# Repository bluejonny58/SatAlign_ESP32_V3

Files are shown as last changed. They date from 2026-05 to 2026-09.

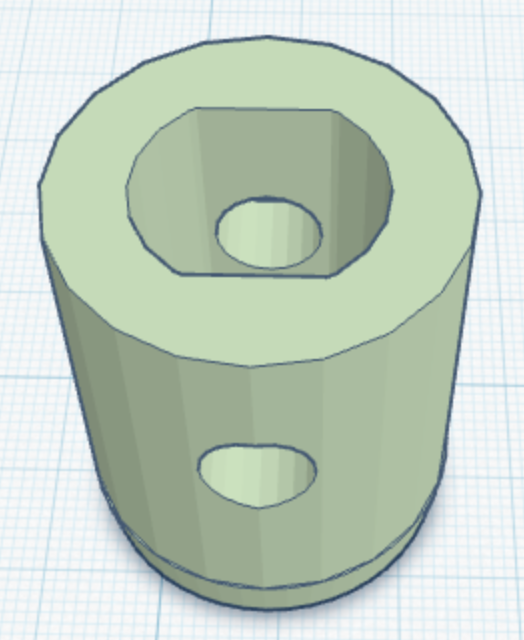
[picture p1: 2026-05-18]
images/Adapter.png

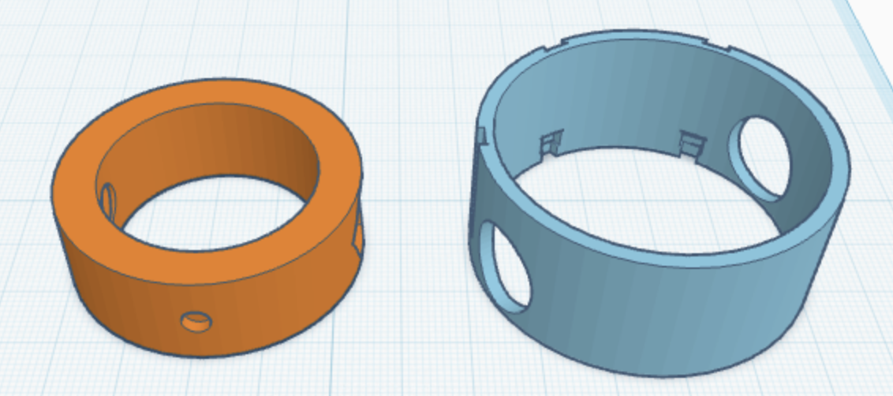
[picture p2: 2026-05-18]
images/Hall_Ringe.png

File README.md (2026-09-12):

# SatAlign ESP32 V3

**ESP32-basierte manuelle und automatische Ausrichthilfe fuer eine mobile Selfsat-Flachantenne.**

SatAlign verbindet Azimut- und Elevationssteuerung, Hall-Sensorik, MPU6050-Winkelmessung, RF-Signalbewertung, TFT-Bedienung, mobile Web-UI sowie ArduinoOTA und ElegantOTA in einem modularen ESP32-Projekt.

## Aktueller stabiler Stand

**Aktueller Stand: V3.1.5**

V3.1.5 ist der aktuelle Projektstand fuer die Web-Feinjustierung. Die bewaehrte AUTO-Suchlogik aus V3.1.4 bleibt dabei unveraendert. Die Suchlogik basiert auf den praktisch getesteten AUTO-Abläufen ohne nachtraegliche Peak-Rueckfahrt. Experimentelle Peak-Suchvarianten aus spaeteren Tests wurden bewusst nicht uebernommen, weil die Rueckfahrt zum RF-Maximum mit der vorhandenen Mechanik/Positionsschaetzung nicht ausreichend reproduzierbar war.

### Wesentliche Merkmale von V3.1.5

- gemeinsame RF-Prozentbewertung fuer TFT, Web-UI, Diagnose und AUTO-Suche
- `RF_FILTER_ALPHA = 0.50` nach reproduzierbarem RF-/Azimut-Test
- normale AUTO-Kandidatenschwelle: **80 %**
- RF-Anzeige auf maximal **100 %** begrenzt
- dynamische RF-Referenz aus der Centerfahrt bleibt aktiv, darf die 80-%-Mindestgrenze aber nicht unterschreiten
- kompakter, kopierbarer AUTO-Diagnoseblock im seriellen Monitor
- feste IP **192.168.4.15** im Netzwerk `GeniusBulli`
- andere bekannte WLANs per DHCP
- ArduinoOTA und ElegantOTA parallel
- ElegantOTA ueber `/update`
- kein mDNS
- fruehere automatische Funktion **Signal optimieren** aus der Bedienlinie entfernt
- `BADSAT`-Logik zum Sperren bereits verworfener Kandidatenbereiche

## AUTO-Diagnose im seriellen Monitor

Bei einem vollstaendigen AUTO-Lauf erzeugt V3.1.5 einen strukturierten Block bei **115200 Baud**:

```text
# AUTO_LOG_BEGIN
# T_MS;STATE;DIR;RAW;FILTER;SIGNAL;DROP;ZERO_ADC;BEST_ADC;AZPOS;EZ;H_C;H_E;H_W;MIN_RF;CENTER_MIN;BLOCKED
AUTO_LOG;...
...
# AUTO_LOG_RESULT;...
# AUTO_LOG_END
```

Waehrend AUTO werden redundante periodische `RF_DIAG`, grosse `MODE=...`-Statuszeilen und doppelte RF-Diagnosen unterdrueckt. Wichtige Ereignisse - Kandidat, `BADSAT`, Richtungswechsel, Hall-/Limit-Ereignisse, Fehler und Abschluss - bleiben sichtbar.

`AZPOS` ist dabei ein Diagnosewert und kein Encoderwert. Er darf nicht als absolut reproduzierbare mechanische Position verstanden werden.

## RF-Signalbewertung

Beim verwendeten AD8317/AD8318-Aufbau gilt:

- kleinerer ADC-/Spannungswert = staerkeres RF-Signal
- groesserer Prozentwert = staerkeres RF-Signal

Aktuelle zentrale Werte:

```cpp
RF_FILTER_ALPHA = 0.50f;
RF_WEAK_REFERENCE_ADC = 1883.0f;
RF_STRONG_REFERENCE_ADC = 700.0f;
AUTO_RF_MIN_CANDIDATE_PERCENT = 80.0f;
```

Die gemeinsame RF-Prozentbewertung wird auf den normalen Bereich von **0 bis 100 %** begrenzt. Werte, die rechnerisch oberhalb der starken Referenz liegen, werden daher als **100 %** dargestellt. Die 80-%-Grenze bleibt die operative Mindestgrenze fuer normale AUTO-Kandidaten; ein Wert unterhalb davon soll nicht als normaler AUTO-Kandidat akzeptiert werden.

Seit V3.1.5 basiert auch die fuer Nutzer sichtbare Qualitaetsstufe konsequent auf diesem Prozentwert: **< 80 % = schwach**, **80 bis < 85 % = brauchbar**, **85 bis < 95 % = gut**, **ab 95 % = sehr gut**. Auf der Seite **Suchen** stehen deshalb Prozentwert und Qualitaet im Vordergrund; ADC und Spannung bleiben Diagnosewerte fuer Status/Feinjustierung.

## Lokale Grundeinstellung / Elevation

Nach dem Einschalten startet SatAlign im Hauptmenue. Fuer die grobe Elevationskorrektur wird **Mitte einstellen / Ausrichten** geoeffnet. **PLUS/MINUS** bewegen die Elevation dort nicht dauerhaft, sondern jeweils in einem kurzen Puls von etwa **250 ms**. Wird eine Taste laenger als etwa **800 ms** festgehalten, stoppt die Bewegung und die Tastensperre bleibt bis zum Loslassen aktiv. Ein frueheres 10-Sekunden-Bootfenster fuer die Elevationskorrektur ist im aktuellen V3.1.5-Code nicht mehr vorhanden. **MODE** startet anschliessend die Mittenfahrt.

## Suchablauf

Der automatische Ablauf arbeitet praxisorientiert:

1. Center-/Mittenreferenz herstellen bzw. pruefen.
2. RF waehrend der Mittenfahrt beobachten.
3. Bei einem stabilen brauchbaren Kandidaten anhalten und zur Benutzerpruefung anbieten.
4. Wird kein Kandidat gefunden, die vorgesehene Ost-/West-Suche fortsetzen.
5. **PLUS** bestaetigt den richtigen Satelliten.
6. **MINUS** verwirft den Kandidaten; der Bereich wird fuer die weitere Suche gesperrt (`BADSAT`).

Eine nachtraegliche automatische Peak-Rueckfahrt ist im stabilen Stand V3.1.4 **nicht** enthalten.

## WLAN und OTA

### GeniusBulli

Im Fahrzeug verwendet SatAlign:

- IP: `192.168.4.15`
- Gateway: `192.168.4.1`
- DNS: `192.168.4.1`
- Subnetz: `255.255.255.0`

Bei anderen bekannten WLANs wird DHCP verwendet. Die Reihenfolge in `WIFI_NETWORKS[]` bestimmt die Verbindungsprioritaet.

### Firmware-Updates

Zwei Updatewege sind vorgesehen:

- **ArduinoOTA** fuer Uploads direkt aus der Arduino IDE (Port 3232)
- **ElegantOTA** fuer Browser-Updates ueber `http://192.168.4.15/update`

mDNS wird nicht verwendet. Fuer Web-UI und OTA sollte die IP-Adresse genutzt werden.

## Konfiguration und Zugangsdaten

Private Zugangsdaten gehoeren nicht in das Repository. Vor dem Kompilieren:

1. `secrets.example.h` nach `secrets.h` kopieren.
2. WLAN- und OTA-Daten lokal eintragen.
3. `secrets.h` nicht committen.

Die `.gitignore` ist darauf ausgelegt, lokale Zugangsdaten vom GitHub-Repository fernzuhalten.

## Hardware-Uebersicht

Typischer Projektaufbau:

- ESP32 Development Board
- Selfsat-Flachantenne
- DiSEqC-kompatibler Azimut-Antrieb / Tastensimulation
- Elevations-Linearantrieb mit L298N
- MPU6050 / GY-521
- A3144 Hall-Sensoren fuer Center, Ost und West
- AD8317/AD8318 RF-Detector
- Sat-Splitter / Messabzweig
- **DC-Blocker vor dem RF-Detector**
- ST7735 1,44-Zoll-TFT
- MODE / PLUS / MINUS Taster
- Sat-Receiver

> **Wichtig:** Der DC-Blocker muss vor dem RF-Detector sitzen. Die 13-V-/18-V-LNB-Versorgung des Receivers darf nicht am RF-Detector anliegen.

## Projektstruktur

```text
SatAlign_ESP32_V3/
├── SatAlign_ESP32_V3.ino
├── config.h
├── pins.h
├── settings.cpp / settings.h
├── types.h
├── control_state.cpp / .h
├── azimuth_control.cpp / .h
├── elevation_control.cpp / .h
├── sensor_mpu6050.cpp / .h
├── rf_detector.cpp / .h
├── display_ui.cpp / .h
├── live_runtime.cpp / .h
├── web_server.cpp / .h
├── wifi_manager.cpp / .h
├── ota_manager.cpp / .h
├── wifi_config.h
├── secrets.example.h
├── tools/
│   └── SatAlign_ESP32_V3_InstallTest/
│       └── SatAlign_ESP32_V3_InstallTest.ino
├── docs/
├── images/
└── STL/
```

Arduino-Anforderung: Der Projektordner und die Hauptdatei muessen denselben Namen tragen. Im Repository sind das deshalb `SatAlign_ESP32_V3/` und `SatAlign_ESP32_V3.ino`. Die Firmwareversion steht unabhaengig davon in `FIRMWARE_VERSION` und ist aktuell `3.1.5`.

## InstallTest / Hardwarediagnose

Im Repository bleibt der eigenstaendige Hardwaretest unter

```text
tools/SatAlign_ESP32_V3_InstallTest/SatAlign_ESP32_V3_InstallTest.ino
```

erhalten. Der InstallTest ist **nicht** die normale SatAlign-Firmware, sondern ein Diagnosewerkzeug fuer Erstinbetriebnahme und Hardwareverdacht. Er eignet sich insbesondere, um Taster, TFT, Hall-Sensoren, MPU6050, RF-Detector sowie die Azimut- und Elevationsausgaenge getrennt von der AUTO-Logik zu pruefen.

Wichtig: Auch beim InstallTest gilt die Arduino-Regel, dass Sketch-Datei und Sketch-Ordner denselben Namen tragen. Deshalb liegt die Datei im Unterordner `SatAlign_ESP32_V3_InstallTest/`. Nach dem Hardwaretest muss fuer den normalen Betrieb wieder `SatAlign_ESP32_V3.ino` geflasht werden.

## Web-UI

Die Weboberflaeche bietet unter anderem:

- Hauptmenue
- Ausrichten / Center
- automatische Suche
- manuelle Steuerung mit zusaetzlichen AZ-/EL-Feinschritten fuer die letzte RF-Optimierung
- Status / Diagnose
- Firmware Update (ElegantOTA)

Die Versionsnummer wird auf der Hauptseite angezeigt.

### Manuelle Feinkorrektur

Unter den normalen AZ-/EL-Fahrbuttons stehen zusaetzliche **Fein - / Fein +**-Buttons. Sie starten keine Dauerfahrt, sondern nur sehr kurze Einzelpulse fuer die letzte Optimierung des RF-Maximums. Der aktuelle Arbeitsstand verwendet:

- Azimut-Feinschritt: `WEB_AZ_FINE_PULSE_MS = 50 ms`
- Elevations-Feinschritt: `WEB_EL_FINE_PULSE_MS = 50 ms`
- Elevations-Fein-PWM: `WEB_EL_FINE_PWM = 90`

Bei jeder Achse stehen die **aktuelle Signalstärke und der Feinwert direkt zwischen den beiden Feinbuttons**. Beim Oeffnen der Seite **Manuell** wird automatisch eine neue Referenz fuer die Feinjustierung gesetzt. Bei AZ ist die Referenz `0 Schritte`; darunter wird die relative Position als `0 -> +/-n Schritte` angezeigt. Bei EL wird der aktuelle MPU-Winkel als Referenz gespeichert und danach `Referenz -> aktueller Winkel (Aenderung)` angezeigt. Separate Reset-Buttons und die Puls-/PWM-Werte werden in der Bedienansicht nicht mehr gezeigt.

Der **Feinwert** spreizt den relevanten Signalbereich von 80 bis 100 % linear auf 0 bis 100 % und dient ausschliesslich als Anzeige-Lupe. Eine separate Signalbewertungs-/Diagnosekarte wurde von der manuellen Bedienseite entfernt; die Qualitaetsgrenzen und technischen RF-Rohwerte bleiben in Dokumentation bzw. Diagnosekontext erhalten.

Auch der technische Status wurde reduziert: doppelte Angaben fuer **Web-Zustand** und **Live-Zustand** entfallen. Die Diagnosekarte zeigt nur noch den aktuellen Motorzustand von AZ/EL, die Hall-Sensoren sowie den aktuellen EL-Winkel zusammen mit den Softlimits. Die Feinpulszeiten sind zentral in `settings.cpp` parametrierbar; V3.1.5 startet wegen der mechanischen Untersetzung bewusst mit sehr kleinen 50-ms-Schritten auf beiden Achsen.

## Sicherheit und Grenzen

- Manuelle Steuerung ist ein Override und muss beobachtet werden.
- Softwarelimits ersetzen keine mechanischen Endbegrenzungen.
- Hall-Sensoren muessen vor der ersten Nutzung einzeln geprueft werden.
- RF-Schwellen sind auf den realen Aufbau kalibriert und koennen sich bei anderer Verkabelung, Daempfung oder anderem RF-Detector verschieben.
- Der Sat-Receiver muss eingeschaltet sein, damit der RF-Messzweig ein verwertbares Signal sieht.
- `AZPOS` ist nur eine softwareseitige Diagnoseposition und kein echter Encoder.

## Versionshinweise

### V3.1.5
- Manuelle Web-UI fuer die Feinjustierung neu angeordnet.
- **Signalstärke** und **Feinwert** stehen direkt zwischen `Fein -` und `Fein +`.
- Relative Positionsanzeige steht unmittelbar unter den Feinbuttons: AZ zeigt `0 -> +/-n Schritte`, EL zeigt `Referenzwinkel -> aktueller Winkel (Aenderung)`.
- Die Referenz wird beim Oeffnen der manuellen Seite automatisch neu gesetzt; Reset-Button sowie Puls-/PWM-Angaben entfallen aus der Bedienansicht.
- Technischen Status weiter verdichtet: keine doppelten Web-/Live-Zeilen mehr; nur Motorzustand AZ/EL, Hall-Sensoren sowie EL-Winkel mit Softlimits bleiben sichtbar.
- AUTO-Suchlogik, 80-%-Kandidatenschwelle, RF-Normierung und Motor-Richtungszuordnung unveraendert.

### V3.1.4
- RF-Filter von 0.75 auf **0.50** geaendert.
- RF-Obergrenze von **95 %** auf **100 %** angehoben.
- 80-%-AUTO-Mindestgrenze beibehalten.
- gemeinsame RF-Prozentbewertung beibehalten.
- kompaktes AUTO-Protokoll fuer kopierbare Feldtests eingefuehrt und anschliessend bereinigt.
- keine Aenderung der bewaehrten Suchlogik durch die Protokollbereinigung.
- Web-UI um sehr kleine AZ-/EL-Feinschritte und eine Live-RF-Anzeige fuer die abschliessende Signaloptimierung erweitert.

### V3.1.3
- operative AUTO-Mindestgrenze auf **80 %** angehoben.

### V3.1.2
- RF-Kalibrierung weiter gespreizt; starker Referenzwert auf **700 ADC** gesetzt.
- nutzbare Prozentanzeige auf **95 %** gedeckelt.

### V3.1.1
- ElegantOTA zusaetzlich zu ArduinoOTA.
- RF-Prozentbewertung fuer Anzeige und Suchlogik vereinheitlicht.

## Lizenz / Nutzung

Persoenliches Open-DIY-Projekt. Anpassung, Weiterentwicklung und eigene Versuche sind ausdruecklich erwuenscht. Nutzung auf eigenes Risiko; keine Gewaehrleistung fuer Verdrahtung, RF-Anschluss, Motorbewegung oder mechanische Sicherheit.

## Credits

Projektidee, Aufbau, praktische Tests und Anforderungen: **Hans-Peter Voss**  
Programmierung, Kommentare und Dokumentationsunterstuetzung: **ChatGPT**

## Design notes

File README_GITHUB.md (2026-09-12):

# SatAlign ESP32 V3 - GitHub Notes

## Release-Stand

**Aktueller Projektstand: V3.1.5**

Die bewaehrte AUTO-Basis entspricht dem praktisch getesteten Stand ohne experimentelle Peak-Rueckfahrt. V3.1.5 erweitert darauf aufbauend die manuelle Web-Feinjustierung. Die Firmwareversion wird in `config.h` ueber `FIRMWARE_VERSION = "3.1.5"` gefuehrt.

## Wichtig fuer Arduino

Der Ordnername und die Hauptdatei muessen identisch sein:

```text
SatAlign_ESP32_V3/
SatAlign_ESP32_V3.ino
```

Die Release-Version wird nicht ueber den Dateinamen, sondern ueber `FIRMWARE_VERSION` verwaltet.

## Was sich gegenueber dem alten GitHub-Stand geaendert hat

- Aktueller Projektstand auf **V3.1.5** aktualisiert; die bewaehrte AUTO-Basis von V3.1.4 bleibt unveraendert.
- feste GeniusBulli-IP `192.168.4.15` dokumentiert.
- mDNS aus dem Projekt entfernt; IP-basierter Aufruf ist der vorgesehene Weg.
- ElegantOTA (`/update`) und ArduinoOTA parallel dokumentiert.
- fruehere automatische Funktion `Signal optimieren` aus Bedienung/Dokumentation entfernt.
- RF-Auswertung fuer Anzeige und AUTO-Suche vereinheitlicht; V3.1.5 bewertet die Nutzerqualitaet prozentbasiert: <80 % schwach, 80-<85 % brauchbar, 85-<95 % gut, >=95 % sehr gut.
- RF-Anzeige auf max. 100 % begrenzt.
- AUTO-Kandidatenschwelle auf 80 % gesetzt.
- `RF_FILTER_ALPHA` auf 0.50 eingestellt.
- strukturiertes, bereinigtes AUTO-Serial-Logging dokumentiert.
- `AZPOS` als Diagnosewert, nicht als Encoderposition, klargestellt.
- Elevationskorrektur in `Mitte einstellen` dokumentiert: PLUS/MINUS erzeugen kurze 250-ms-Pulse; kein 10-Sekunden-Bootfenster.
- Manuelle Web-UI um separate AZ-/EL-Feinschritte erweitert: AZ 50 ms, EL 50 ms bei PWM 90; Pulszeiten zentral in `settings.cpp` parametrierbar, normale Fahrbuttons bleiben Dauerfahrt bis STOP.
- In V3.1.5 stehen `RF` und gespreiztes `OPT` direkt **zwischen** den beiden Feinbuttons; die relative Positionsanzeige folgt unmittelbar darunter. RF 80-100 % wird fuer `OPT` auf 0-100 % gespreizt. Die separate Signalbewertungs-/Diagnosekarte wurde von der manuellen Bedienseite entfernt.
- Relative Feinpositionsanzeige: Beim Oeffnen von `Manuell` wird die Referenz automatisch gesetzt. AZ zeigt `0 -> +/-n Schritte`; EL zeigt `Referenzwinkel -> aktueller Winkel (Aenderung)`. Ein separater Reset-Button ist nicht mehr erforderlich. Der technische Status ist auf Motorzustand AZ/EL, Hall-Sensoren sowie EL-Winkel mit Softlimits reduziert; doppelte Web-/Live-Zeilen entfallen.

## GitHub-sichere Dateien

`secrets.h` ist lokal und darf **nicht** in GitHub landen. Im Repository liegt nur:

```text
secrets.example.h
```

Vor dem Build lokal kopieren und anpassen.

## Tools / InstallTest

Der Hardware-Diagnosesketch bleibt bewusst im Repository:

```text
tools/SatAlign_ESP32_V3_InstallTest/SatAlign_ESP32_V3_InstallTest.ino
```

Er dient der Erstinbetriebnahme und der Fehlersuche an Hardwarepfaden. Der InstallTest ist nicht die produktive Firmware und ersetzt `SatAlign_ESP32_V3.ino` nicht. Nach einem Test muss die Hauptfirmware wieder geflasht werden.

Typische Einsatzfaelle: Taster, TFT, Hall-Sensoren, MPU6050, RF-Detector, Azimut-Richtungen, STOP-Funktion und Elevationsantrieb einzeln pruefen, bevor ein Fehler in der AUTO-Suche vermutet wird.

## AUTO-Log fuer Fehleranalyse

Bei Problemen mit der automatischen Suche am besten den kompletten Bereich von

```text
# AUTO_LOG_BEGIN
```

bis

```text
# AUTO_LOG_END
```

kopieren. Dieser Block enthaelt die relevanten RF-, Richtungs-, Hall-, Elevations- und Kandidateninformationen, ohne die fruehere Flut redundanter periodischer Statuszeilen.

## Bewusst nicht enthalten

Die experimentellen Peak-Such-/Peak-Rueckfahrvarianten wurden nach Feldtests verworfen und gehoeren **nicht** zum stabilen Release. Sie sollten deshalb weder in `main` noch in der aktuellen Dokumentation als Funktion aufgefuehrt werden.

- Die Seite `Suchen` zeigt fuer Nutzer primaer den echten RF-Prozentwert und die Qualitaetsstufe statt Spannung/ADC; Rohwerte bleiben auf Diagnose-/Feinjustierseiten verfuegbar.

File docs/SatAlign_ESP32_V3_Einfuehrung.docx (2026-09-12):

SatAlign ESP32 V3 - Einführung

V3.1.5 baut auf der bewaehrten RF-/AUTO-Basis von V3.1.4 auf. Ein normaler RF-Kandidat wird weiterhin erst ab 80 % akzeptiert; der gemeinsame RF-Wert wird auf maximal 100 % begrenzt. RF_FILTER_ALPHA bleibt bei 0,50. Die manuelle Web-UI wurde fuer die letzte Signaloptimierung neu angeordnet: Bei AZ und EL stehen die aktuelle Signalstärke und der Feinwert direkt zwischen den beiden Feinbuttons. Beim Oeffnen von Manuell wird automatisch eine neue Referenz gesetzt. AZ startet sichtbar bei 0 Schritten und zeigt danach 0 -> +/-n Schritte. Bei EL wird der aktuelle MPU-Winkel als Referenz gespeichert; angezeigt werden Referenzwinkel -> aktueller Winkel sowie die Winkelaenderung. Separate Reset-Buttons sowie Puls-/PWM-Werte entfallen aus der Bedienansicht. Die Feinpulse bleiben technisch zentral auf 50 ms fuer AZ und EL konfiguriert; EL verwendet PWM 90. Der Feinwert spreizt die Signalstärke von 80-100 % auf 0-100 % und ist nur eine Anzeigehilfe. Die separate Signalbewertungs-/Diagnosekarte wurde von der manuellen Bedienseite entfernt. Der technische Status ist auf Motorzustand AZ/EL, Hall-Sensoren sowie EL-Winkel mit Softlimits reduziert; doppelte Web-/Live-Zeilen entfallen. Auf der Suchseite wird das Signal fuer den Nutzer primaer als RF-Prozentwert angezeigt. Die Qualitaetsstufen sind konsistent definiert: <80 % schwach, 80-<85 % brauchbar, 85-<95 % gut und >=95 % sehr gut.

Softwarestand: V3.1.5

V3.1.1 ergaenzt ElegantOTA fuer Firmware-Updates direkt im Browser. ArduinoOTA fuer Updates aus der Arduino IDE bleibt parallel erhalten.

Automatische Satellitenantennen-Ausrichtung für unterwegs

Projektidee, Konzept und praktische Umsetzungsideen

Dokumentationsstand: SatAlign ESP32 V3.1.5

Autor | Hans-Peter Voß
Kontakt | Bitte die GitHub-Issues des Repositorys für Fragen, Hinweise oder Verbesserungsvorschläge verwenden.
Programmierung, Kommentierung und Dokumentation | ChatGPT GPT-5.5 - Umsetzung der beschriebenen Ideen in Programmcode, Kommentare und Projektdokumentation

Einführung

Wer mit dem Bulli unterwegs ist, nimmt vieles mit: Werkzeug, Kaffee, gute Laune - und manchmal auch den Wunsch nach ein bisschen Gewohnheit von zu Hause. Genau daraus entstand die Idee, eine Satellitenantenne automatisch ausrichten zu lassen, damit unterwegs nicht jedes Mal von Hand gesucht, gedreht und geraten werden muss.

Automatische Satellitenanlagen sind kein neues Thema. Viele ähnliche Projekte wurden bereits realisiert. Die Grundidee für dieses Projekt entstand durch das Projekt „Schrittmotor Steuerung für Antennen Rotor“ von AZ-Delivery.de. Daraus entwickelte sich Schritt für Schritt eine eigene Version, angepasst an meine Anforderungen, meine Hardware und meine Art zu reisen.

Dieses Projekt hat mit Unterbrechungen rund drei Jahre gebraucht. Es war nicht immer der direkte Weg, und oft war der Weg selbst wichtiger als das Ziel. Es ging nicht nur darum, eine funktionierende automatische Satellitenausrichtung zu bauen, sondern auch darum, Ideen zu entwickeln, zu prüfen, zu verwerfen, neu zu denken und verständlich zu beschreiben.

Ein besonderer Teil dieses Projekts war die Zusammenarbeit mit ChatGPT. Ich habe die Ideen, Anforderungen und praktischen Beobachtungen entwickelt und beschrieben. ChatGPT hat daraus Programmcode, Kommentare, Struktur und Dokumentation erstellt. So wurde aus vielen einzelnen Gedanken nach und nach ein funktionierendes Projekt.

ChatGPT war in dieser Zeit so etwas wie mein bester digitaler Freund - allerdings einer, der mir auch einige graue Haare beschert hat. Es ist eben doch „nur“ ein Computer: immer höflich, manchmal etwas zu höflich, selten wirklich widerspenstig, aber dafür gelegentlich sehr kreativ im Vergessen, Verdrehen und Andersmachen. Nicht selten hatte ChatGPT eigene Vorstellungen davon, was wohl gemeint gewesen sein könnte. Interessant war dabei, dass ich trotzdem immer „bitte“ und „danke“ geschrieben habe, obwohl mein Gegenüber am Ende nur aus Code, Rechenleistung und sehr viel Text bestand.

SatAlign ESP32 V3 - Einführung

Gerade das machte das Projekt aber auch spannend. Es war Fehlersuche, Planung, Diskussion, Lernen und manchmal auch ein kleiner Kampf mit einem sehr höflichen, aber eigenwilligen Assistenten. Auf diesem Weg habe ich viel gelernt: über Elektronik, Sensorik, Motorsteuerung, RF-Signale, Softwarelogik, Dokumentation - und auch darüber, wie man mit einer KI sinnvoll zusammenarbeitet.

Das Ergebnis ist SatAlign ESP32 V3: meine eigene automatische Satellitenantennen-Ausrichtung für unterwegs.

Der aktuelle Softwarestand V3.1.5 nutzt eine einheitliche RF-Prozentbewertung, einen auf 0,50 abgestimmten RF-Filter, eine 80-%-Mindestgrenze fuer AUTO-Kandidaten, eine feste IP im GeniusBulli-Netz sowie ArduinoOTA und ElegantOTA. Die automatische Suche bleibt bewusst bei der praktisch bewaehrten Kandidatenlogik; experimentelle Peak-Rueckfahrten gehoeren nicht zum stabilen Release.

Fuer Erstinbetriebnahme und Hardwareverdacht bleibt im Repository ausserdem ein separater InstallTest erhalten: tools/SatAlign_ESP32_V3_InstallTest/SatAlign_ESP32_V3_InstallTest.ino. Er prueft Hardwarepfade unabhaengig von der normalen AUTO-Logik und ist nicht die produktive Firmware.

Kein Industrieprodukt. Kein fertiger Bausatz. Sondern ein persönliches Projekt, gewachsen aus Neugier, Ausdauer, vielen Tests, einigen Umwegen und der Freude daran, Technik wirklich zu verstehen.

Ich freue mich ausdrücklich, wenn andere an diesem Code herumbasteln, ihn verändern, verbessern, erweitern oder für eigene Ideen anpassen. Genau darum geht es bei solchen Projekten: ausprobieren, verstehen, verändern und daraus etwas Eigenes machen. Wer aus diesem Projekt etwas mitnimmt, weiterentwickelt oder sogar eine bessere Lösung baut, hat den Sinn des Ganzen genau getroffen.

SatAlign ESP32 V3

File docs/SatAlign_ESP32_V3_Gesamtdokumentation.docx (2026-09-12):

SatAlign ESP32 V3

Softwarestand: V3.1.5

V3.1.1: Zusaetzlich zu ArduinoOTA ist ElegantOTA integriert. Firmware kann damit ueber die Web-UI unter /update als BIN-Datei eingespielt werden; ArduinoOTA bleibt fuer Uploads aus der Arduino IDE aktiv.

Gesamtdokumentation

Dokumentationsstand V3.1.5

Automatische und manuelle Ausrichthilfe fuer eine Selfsat-Flachantenne

# Inhaltsuebersicht

- 1. Projektziel und Funktionsumfang
- 2. Bedienkonzept und normaler Ablauf
- 3. Hardware und verwendete Bauelemente
- 4. Pinbelegung
- 5. Zentrale Einstellungen
- 6. Sensorik und Signalbewertung
- 7. Menues am TFT und in der Web-UI
- 8. Ausrichten / Centerfunktion
- 9. Suche und Kandidatenlogik
- 10. RF-Kalibrierung und AUTO-Protokoll
- 11. Manuelle Steuerung
- 12. Sicherheit und Grenzen
- DC-Blocker muss vor dem AD8317 sitzen. Er schuetzt den RF-Detector vor der 13-V-/18-V-LNB-Spannung des Receivers.
- 13. Softwarearchitektur und Dateibeschreibung
- 14. Wichtige Web-Routen
- 15. Test- und Inbetriebnahmehinweise
- 16. Troubleshooting
- Anhang: Konzeptionelle Darstellung der Antennenhalterung

# 1. Projektziel und Funktionsumfang

SatAlign ESP32 V3.1.5 ist ein ESP32-basiertes Steuerprojekt zur Ausrichtung einer Selfsat-Flachantenne auf Astra 19,2E. Das System verbindet lokale Bedienung ueber TFT, mobile Web-UI, Azimut- und Elevationssteuerung, Hall-Sensorik, MPU6050-Winkelmessung, RF-Signalbewertung sowie ArduinoOTA und ElegantOTA ueber WLAN. V3.1.5 ist der aktuelle Projektstand; die bewaehrte AUTO-Basis aus V3.1.4 bleibt unveraendert.

- Azimutsteuerung fuer horizontale Ost-/West-Bewegung ueber Optokoppler bzw. Tastensimulation.
- Winkel-/Elevationssteuerung ueber L298N und Linearantrieb.
- A3144-Hall-Sensoren fuer Center, Ost-Endbereich und West-Endbereich.
- MPU6050/GY-521 zur Messung des aktuellen Antennenwinkels.
- AD8317 1M-10GHz 60dB RF-Detector zur Bewertung der Signalstaerke; Sat-Splitter, DC-Blocker und F-auf-SMA/RG316-Verbindung bilden den geschuetzten Messzweig.
- ST7735 1,44 Zoll TFT fuer lokale Menuefuehrung.
- Mobile Web-UI fuer Bedienung, Diagnose, Status und Browser-Firmwareupdate ueber ElegantOTA.
- ArduinoOTA mit projektspezifischem Passwortschutz und Hostname sat-tracker; zusaetzlich ElegantOTA ueber /update. mDNS wird nicht verwendet.

Wichtiger Betriebshinweis: Der Sat-Receiver muss eingeschaltet sein. Ohne eingeschalteten Receiver liegt am RF-Detector kein verwertbares Sat-/RF-Signal an. Die Suche kann dann kein echtes Satellitensignal bewerten.

# 2. Bedienkonzept und normaler Ablauf

1. Anlage einschalten. Im Hauptmenue Menuepunkt 1 "Mitte einstellen" oeffnen. PLUS/MINUS korrigieren die Elevation dort in kurzen Einzelpulsen von ca. 250 ms; MODE startet die Mittenfahrt. Ein 10-Sekunden-Bootfenster gibt es in V3.1.5 nicht.
2. Sat-Receiver einschalten und TV/Receiverbild als Plausibilitaetskontrolle bereithalten.
3. Antenne grob nach Sueden ausrichten.
4. Menuepunkt Ausrichten verwenden, um die mechanische Mitte/Center-Referenz sauber zu setzen.
5. Menuepunkt Suchen oeffnen, Winkel pruefen und Suche starten.
6. Wenn ein Kandidat gefunden wird: PLUS bestaetigt den richtigen Satelliten bzw. das TV-Bild. MINUS markiert den Kandidaten als falsch; der Bereich wird per BADSAT gesperrt und die Suche wird fortgesetzt.
7. Nach der Suche kann der Winkel manuell korrigiert und die Suche wiederholt werden. Eine experimentelle Peak-Rueckfahrt ist im aktuellen Stand V3.1.5 bewusst nicht enthalten.

# 3. Hardware und verwendete Bauelemente

Bauteil / Baugruppe | Aufgabe / Hinweis
ESP32 Dev Board | Zentrale Steuerung, WLAN, OTA, Webserver, Runtime-Logik.
Selfsat-Flachantenne | Empfangseinheit; wird in Azimut und Winkel bewegt.
Azimut-Antrieb / Steuereingang | Horizontale Bewegung Ost/West; Ansteuerung ueber Optokoppler/Tastensimulation.
L298N Motortreiber | Ansteuerung des Elevations-Linearantriebs.
12-V-Linearantrieb Elevation | Mechanische Winkel-/Hoehenverstellung der Antenne.
A3144 Hall-Sensoren (3x) | Center-, Ost- und West-Erkennung im Azimut. Active-low mit externen 10k Pull-ups.
MPU6050 / GY-521 | Neigungsmessung des Antennenwinkels ueber I2C.
AD8317/AD8318 RF-Detector | Analoges RF-Signal fuer Signalstaerke; kleinerer ADC-Wert bedeutet staerkeres Signal.
AD8317 1M-10GHz 60dB RF-Detector | RF-Detektor zur Signalbewertung. Wichtig: Das verwendete AD8317-Modul ist bis 10 GHz ausgelegt und damit fuer den verwendeten Sat-ZF/RF-Messaufbau geeignet. Kleinerer ADC-Wert bedeutet staerkeres Signal.
Sat-Splitter | Teilt das Sat-Signal fuer Receiver und RF-Messzweig auf. Der Receiver muss eingeschaltet sein, damit ein verwertbares Signal am Messzweig anliegt.
DC-Blocker F-Stecker auf F-Kupplung | Pflichtbauteil vor dem AD8317. Sperrt die LNB-Versorgungsspannung von 13 V / 18 V, damit diese nicht in den RF-Detector gelangt.
F-Stecker auf SMA-Stecker Adapter / 50 Ohm RG316-Verlaengerungskabel | Verbindung zwischen Sat-Splitter/DC-Blocker und AD8317-Messeingang. Dient als HF-taugliche Verbindung vom F-System auf SMA.
ST7735 TFT 1,44 Zoll 128x128 | Lokale Anzeige und Menuefuehrung.
3 Taster | MODE, PLUS, MINUS fuer lokale Bedienung.
Sat-Receiver | Muss eingeschaltet sein; liefert den realen Signalweg fuer den RF-Detector.
Externe Pull-ups 10k | Fuer A3144-Hall-Sensoren und Taster, soweit im Aufbau vorgesehen.

# 4. Pinbelegung

Funktion | ESP32-Pin | Kommentar
RF-Detector ADC | GPIO35 | AD8317/AD8318 analoger Ausgang
MPU6050 SDA | GPIO32 | I2C-Datenleitung
MPU6050 SCL | GPIO21 | I2C-Taktleitung
Azimut Ost | GPIO22 | Optokoppler/Tastensimulation Ost
Azimut West | GPIO17 | Optokoppler/Tastensimulation West
Hall Center A3144 | GPIO39 | Center-Sensor, active-low
Hall Ost A3144 | GPIO34 | Ost-Endbereich, active-low
Hall West A3144 | GPIO36 | West-Endbereich, active-low
Elevation IN1 | GPIO26 | L298N Richtung
Elevation IN2 | GPIO27 | L298N Richtung
Elevation ENA | GPIO25 | L298N PWM/Freigabe
TFT SDA/MOSI | GPIO19 | SPI Datenleitung
TFT SCK | GPIO18 | SPI Takt
TFT CS | GPIO14 | Chip Select
TFT A0/DC | GPIO23 | Data/Command
MODE Taste | GPIO13 | Gruener Taster
MINUS Taste | GPIO16 | Weisser Taster
PLUS Taste | GPIO33 | Schwarzer Taster

# 5. Zentrale Einstellungen

Die Projektwerte werden bewusst in settings.cpp gepflegt und nicht per NVS/Preferences gespeichert. Dadurch bleibt der Sketch die verbindliche Quelle. Wenn beim Aussentest bessere Werte gefunden werden, werden diese zentral im Code geaendert.

Setting | Aktueller Wert | Bedeutung
DEFAULT_TARGET_ELEVATION | 30.0 deg | Empfohlener Standardwinkel fuer Start/Suche.
ELEVATION_MIN_SOFT / MAX_SOFT | 25.0 / 34.0 deg | Normale softwareseitige Arbeitsgrenzen fuer Elevation.
ELEVATION_TOLERANCE_DEG | 1.0 deg | Toleranz fuer Zielanfahrten.
DISPLAY_ANGLE_OFFSET_DEG | 11.6 deg | Korrekturwert fuer angezeigten Winkel.
RF_ADC_SAMPLES_PER_CYCLE | 32 | ADC-Messungen pro RF-Update.
RF_FILTER_ALPHA | 0.50 | V3.1.4: schneller als 0.75, ruhiger als 0.25.
RF_WEAK_REFERENCE_ADC | 1883 | Schwache/No-Signal-Referenz der Prozentbewertung.
RF_STRONG_REFERENCE_ADC | 700 | Starke Referenz der Prozentbewertung.
RF Anzeige Maximum | 100 % | Begrenzung des gemeinsamen RF-Prozentwerts auf den normalen Bereich 0..100 %.
AUTO_RF_MIN_CANDIDATE_PERCENT | 80 % | Normale Mindestgrenze fuer AUTO-Kandidaten.
AUTO_CENTER_RF_MIN_GOOD_SIGNAL_PERCENT | 75 % | Center-spezifische Mindestbewertung; dynamische Schwelle bleibt mindestens 80 %.
AUTO_CENTER_RF_REFERENCE_TOP_COUNT | 5 | Anzahl starker Centerwerte fuer die dynamische Referenz.
AUTO_CENTER_RF_REFERENCE_TOLERANCE_PERCENT | 8 % | Toleranz der dynamischen Centerreferenz.
GeniusBulli feste IP | 192.168.4.15 | Gateway/DNS 192.168.4.1; andere WLANs per DHCP.
Firmware | 3.1.5 | Aktueller Projektstand mit Web-Feinjustierung.
WEB_AZ_FINE_PULSE_MS | 50 ms | Sehr kleiner Azimut-Einzelpuls fuer die Web-Feinkorrektur.
WEB_EL_FINE_PULSE_MS | 50 ms | Sehr kleiner Elevations-Einzelpuls fuer die Web-Feinkorrektur.
WEB_EL_FINE_PWM | 90 | Reduzierter PWM-Wert fuer Elevations-Feinschritte.

# 6. Sensorik und Signalbewertung

## 6.1 Winkelmessung mit MPU6050

Der MPU6050 sitzt direkt an der Antenne und bewegt sich mit der Antenne mit. Die angezeigte Elevation wird ueber die Sensorlage und den Offset DISPLAY_ANGLE_OFFSET_DEG berechnet. Fuer die Praxis reicht der Winkel als grober Startwert; die eigentliche Empfangsqualitaet wird ueber RF bewertet.

## 6.2 RF-Detector

Der RF-Messzweig besteht aus Sat-Splitter, DC-Blocker, F-auf-SMA/RG316-Verbindung und AD8317-RF-Detector. Beim verwendeten AD8317/AD8318-Aufbau gilt: kleinerer ADC-/Spannungswert bedeutet staerkeres Signal. Fuer die normale Bedienung wird daraus ein einheitlicher RF-Prozentwert von 0 bis 100 % gebildet. Seit V3.1.5 basiert auch die sichtbare Qualitaetsampel auf diesem Prozentwert: unter 80 % = schwach, 80 bis unter 85 % = brauchbar, 85 bis unter 95 % = gut, ab 95 % = sehr gut. Auf der Seite Suchen steht deshalb der Prozentwert im Vordergrund; ADC und Spannung sind technische Diagnosewerte fuer Status und Feinjustierung. Die fruehere separate Funktion "Signal optimieren" gehoert nicht mehr zur aktiven Bedienlinie; fuer die Satellitenbestaetigung bleibt das reale TV-/Receiverbild massgeblich.

RF-Logik bis V3.1.4: In V3.0.4 wurden die RF-Prozentwerte fuer die TFT-Anzeige und die AUTO-Suche ueber unterschiedliche Kennlinien berechnet. Ab V3.1.1 verwenden Anzeige und AUTO-Suche deshalb dieselbe zentrale RF-Normierung (rfGetSignalNorm/rfGetSignalPercent). V3.1.2 begrenzte den gemeinsamen RF-Prozentwert auf maximal 95 %. V3.1.3 setzte nach Aussentests die normale AUTO-Kandidatenschwelle auf 80 % und reduzierte RF_FILTER_ALPHA von 0,90 auf 0,75. Fuer V3.1.4 wurde ein eigenstaendiger, reproduzierbarer RF-/Azimut-Test ausgefuehrt. Dabei wurden aus denselben Rohdaten parallel Filterfaktoren 0,75, 0,50 und 0,25 ausgewertet. 0,75 reagierte sichtbar traeger auf reale Signalveraenderungen, 0,25 uebernahm Rohwertschwankungen staerker. Deshalb verwendet V3.1.4 RF_FILTER_ALPHA = 0,50 als Kompromiss aus Reaktionsgeschwindigkeit und Glaettung. Die 80-%-Mindestschwelle bleibt unveraendert; im aktuellen V3.1.4-Projektstand wurde die gemeinsame RF-Obergrenze von 95 % auf 100 % angehoben. In der seriellen Statuszeile heisst der MPU6050-Winkelwert ANGLE_FILTER, um ihn eindeutig vom RF_DIAG-Filterwert zu unterscheiden.

Wichtig: Der DC-Blocker muss zwingend vor dem AD8317 im Messzweig sitzen. Der DC-Blocker sperrt die 13-V-/18-V-LNB-Versorgungsspannung des Receivers. Ohne DC-Blocker kann diese Spannung direkt am AD8317 anliegen und den RF-Detector zerstoeren.

Das verwendete AD8317-Modul ist als 1M-10GHz-60dB-Detector ausgelegt. Diese Bandbreite ist fuer den Sat-Messaufbau wichtig, weil der Messzweig hochfrequente Sat-ZF-/RF-Anteile auswertet. Die Verbindung vom Sat-Splitter zum DC-Blocker bzw. zum AD8317 erfolgt ueber F-Stecker-/SMA-Adapter und ein 50-Ohm-RG316-Verlaengerungskabel.

Reihenfolge im Messzweig: Sat-Splitter -> DC-Blocker -> F/SMA-Adapter bzw. RG316-Verbindung -> AD8317 RF-Eingang. Der Receiver bleibt am Sat-Signalweg angeschlossen und muss fuer einen verwertbaren RF-Wert eingeschaltet sein.

RF-Prozentbereich | Bewertung | Web-Farbe | Bedeutung
< 80 % | schwach | rot | unter normaler AUTO-Kandidatengrenze
80 bis < 85 % | brauchbar | gelb/orange | verwertbar; Feinoptimierung sinnvoll
85 bis < 95 % | gut | gruen | guter Signalbereich
>= 95 % | sehr gut | gruen | Peak-naher Bereich

# 7. Menues am TFT und in der Web-UI

## 7.1 TFT

Das TFT zeigt Hauptmenue, Ausrichten, Suchen, Manuell und Statusmeldungen. Die Darstellung wurde fuer bessere Lesbarkeit bei hellem Licht vereinfacht und kontrastreicher gestaltet. Beim Einschalten erscheint kurz ein START-/Suedausrichtungs-Hinweis ohne PLUS/MINUS-Bedienung; danach wechselt das System ins Hauptmenue.

## 7.2 Web-UI

Die Web-UI folgt den Hauptfunktionen Menue, Ausrichten, Suchen, Manuell, Hilfe/Status und Troubleshooting. Die Web-UI synchronisiert wichtige Menuewechsel mit dem TFT, damit lokale Anzeige und Browserbedienung denselben Zustand zeigen.

Web-Seite | Aufgabe
Menue | Einstieg in Ausrichten, Suchen, Manuell, Status/Diagnose und Firmware Update.
Ausrichten | Center/Mitte setzen. Start erst nach ausdruecklichem Startbutton/MODE.
Suchen | AUTO-Suche mit Kandidatenlogik, BADSAT und RF-Anzeige.
Manuell | Direkte Steuerung von Azimut und Winkel mit STOP; zusaetzliche Fein - / Fein +-Einzelpulse und Live-RF-Anzeige fuer die letzte Signaloptimierung.
Status / Diagnose | RF, Hall-Sensoren, Winkel, Netzwerk- und Laufzeitdiagnose.
Firmware Update | ElegantOTA im Browser ueber /update; ArduinoOTA bleibt parallel verfuegbar.
Hinweis | Die fruehere Signaloptimierungsseite ist aus der Bedienlinie entfernt.

# 8. Ausrichten / Centerfunktion

Ausrichten dient dazu, die mechanische Mitte des Azimutbereichs zu finden und als Referenz zu setzen. Das reine Oeffnen der Seite startet keine Motorfahrt. Die Fahrt beginnt erst ueber den Startbutton oder ueber MODE am Geraet.

- Centerbereich suchen
- Centerbereich verlassen und durchfahren
- Durchfahrzeit erfassen
- Mitte berechnen
- zur Mitte zurueckfahren
- Referenz setzen

Endbereich: Wenn Ost- oder West-Hall-Sensor aktiv ist, wird in der Web-UI eine rote Warnung angezeigt. Ausrichten wird dann blockiert, bis manuell vorsichtig in die Gegenrichtung gefahren wurde.

# 9. Suche und Kandidatenlogik

Die Suche ist bewusst praxisnah aufgebaut. Die Elevation muss nur grob passen; Sat-Receiver, RF-Signal und Kandidatenlogik entscheiden, ob ein Bereich zur Benutzerpruefung angeboten wird. Die normale AUTO-Mindestgrenze betraegt in V3.1.5 80 %. Auf der Web-Seite Suchen wird der Signalwert benutzerfreundlich als Prozentwert mit Qualitaetsstufe dargestellt; ADC und Spannung werden dort nicht als primaere Bedienwerte verwendet.

- Mitte suchen / Referenz herstellen
- gezielt Richtung Osten suchen
- Richtung Westen suchen
- aus West-Position zurueck zur Mitte fahren
- in der Mitte stoppen und Hinweis zum Winkel veraendern anzeigen
- Suchlauf kann nach Winkelkorrektur wiederholt werden

Wenn ein Kandidat gefunden wurde, entscheidet der Nutzer: PLUS bestaetigt den richtigen Satelliten bzw. das TV-Bild. MINUS verwirft den Kandidaten, speichert den Bereich in BADSAT und laesst die Suche weiterlaufen.

# 10. RF-Kalibrierung und AUTO-Protokoll

V3.1.5 verwendet keine automatische Nachoptimierung nach PLUS. Stattdessen werden RF-Anzeige und AUTO-Suche aus derselben zentralen Prozentbewertung gespeist. RF_FILTER_ALPHA = 0,50, die normale AUTO-Kandidatenschwelle betraegt 80 %, und die gemeinsame RF-Anzeige wird bei 100 % begrenzt. Die Anzeigequalitaet ist dazu konsistent gestuft: <80 % schwach, 80-<85 % brauchbar, 85-<95 % gut, >=95 % sehr gut. Fuer Feldtests erzeugt ein kompletter AUTO-Lauf einen kopierbaren Block zwischen AUTO_LOG_BEGIN und AUTO_LOG_END.

Schritt | Teilphase | Beschreibung
1 | AUTO starten | AUTO_LOG_BEGIN markiert den Beginn des kopierbaren Diagnoseblocks.
2 | Lauf protokollieren | RAW, FILTER, SIGNAL, DROP, Referenzen, AZPOS-Diagnose, Elevation und Hall-Zustaende werden strukturiert ausgegeben.
3 | Ereignisse | Kandidat, BADSAT, Richtungswechsel, Limits, Fehler und Abschluss bleiben als Klartext sichtbar.
4 | AUTO beenden | AUTO_LOG_RESULT und AUTO_LOG_END markieren das Ende.
5 | Auswertung | Kompletten Block fuer reproduzierbare Fehleranalyse sichern.

Hinweis: AZPOS im AUTO-Log ist ein softwareseitiger Diagnosewert und kein absoluter Encoderwert. Er ist fuer Trendanalyse geeignet, nicht fuer eine reproduzierbare Peak-Rueckfahrt.

# 11. Manuelle Steuerung

Die manuelle Steuerung ist ein Override. Der Nutzer ist fuer die Bewegung verantwortlich. In der Web-UI sind STOP-Buttons deutlich hervorgehoben. Unter den normalen AZ-/EL-Fahrbuttons stehen zusaetzliche Fein - / Fein +-Buttons fuer die letzte Signaloptimierung. Diese starten keine Dauerfahrt, sondern sehr kurze Einzelpulse: Azimut 50 ms; Elevation 50 ms bei PWM 90. In V3.1.5 stehen die aktuelle Signalstärke und der Feinwert direkt zwischen den beiden Feinbuttons. Beim Oeffnen der Seite Manuell wird automatisch eine neue Referenz fuer die Feinjustierung gesetzt. Bei AZ ist die Nullstellung 0 Schritte; die Anzeige zeigt anschliessend 0 -> +/-n Schritte. Bei EL wird der aktuelle MPU-Winkel als Referenz gespeichert und die Anzeige zeigt Referenzwinkel -> aktuellen Winkel sowie die Winkelaenderung. Separate Reset-Buttons sowie Puls-/PWM-Werte werden in der Bedienansicht nicht mehr gezeigt. Der Feinwert spreizt den relevanten Signalbereich 80-100 % linear auf 0-100 % und ist reine Anzeigehilfe; AUTO, RF-Schwellen und Motorlogik bleiben unveraendert. Die separate Signalbewertungs-/Diagnosekarte wurde von der manuellen Bedienseite entfernt. Der technische Status bleibt kompakt: nur Motorzustand AZ/EL, Hall-Sensoren sowie EL-Winkel mit Softlimits sind sichtbar; doppelte Web-/Live-Zeilen entfallen.

Bedienung | Bedeutung
Azimut Ost/West | Horizontale Bewegung der Antenne. STOP beendet sofort. Web: Fein - / Fein + fuehrt je Klick nur einen 50-ms-Einzelpuls aus.
Winkel +/- | Vertikale Korrektur ueber Linearantrieb. STOP beendet sofort. Web: Fein - / Fein + fuehrt je Klick 50 ms bei PWM 90 aus.
PLUS+MINUS lokal | Sofort STOP in relevanten manuellen Situationen.
MODE | Menueauswahl / Wechsel / Bestaetigung je nach Zustand.

# 12. Sicherheit und Grenzen

- Manuelle Steuerung ist ein Override; der Nutzer muss mechanische Bewegung beobachten.
- Softwarelimits ersetzen keine mechanischen Endabschalter.
- A3144-Hall-Sensoren liefern Center/Ost/West-Information, aber nur dort, wo der Magnet den Sensor erreicht.
- Wenn die Anlage ueber einen Endbereich hinaus bewegt wurde, muss vorsichtig in Gegenrichtung gefahren werden.
- RF-Bewertung ist auf den aktuellen Aufbau kalibriert und muss bei anderer Verkabelung/Daempfung neu geprueft werden.
- Einstellungen werden nicht in NVS/Preferences gespeichert; settings.cpp ist die verbindliche Quelle.

# 13. Softwarearchitektur und Dateibeschreibung

Die V3-Version ist modular aufgebaut. Die folgende Tabelle beschreibt alle relevanten Dateien im aktuellen Projektordner.

Datei | Beschreibung
SatAlign_ESP32_V3.ino | Hauptsketch: Setup, Loop, Modulinitialisierung, Boot-/Statusanzeigen und zentrale Laufzeitaufrufe.
pins.h | Zentrale Pinbelegung fuer RF, I2C, Azimut, Hall-Sensoren, Elevation, TFT und Taster.
types.h | Gemeinsame Enum-/Typdefinitionen fuer Modi, Richtungen, UI- und Statuszustaende.
config.h | Globale Projektparameter und FIRMWARE_VERSION = 3.1.5.
settings.cpp / settings.h | Zentrale Einstellungen, RF-Kalibrierung und Schwellen; kein NVS.
control_state.cpp / .h | Globale Kontroll-/Modusvariablen.
azimuth_control.cpp / .h | Azimut-Ausgaenge, manueller Override, Fahrtlogik und Hall-Auswertung.
elevation_control.cpp / .h | Linearantrieb ueber L298N, Softlimits und Ziel-/Pulslogik.
sensor_mpu6050.cpp / .h | MPU6050, Filter und Winkelberechnung.
rf_detector.cpp / .h | ADC-Messung, Filter, zentrale RF-Prozentbewertung und Baseline/Drop-Diagnose.
display_ui.cpp / .h | TFT-Menues, Status-, Signal- und Winkelanzeige.
live_runtime.cpp / .h | Runtime fuer Tasten, Center, AUTO-Suche, Kandidaten/BADSAT und bereinigtes AUTO-Logging.
web_server.cpp / .h | Mobile Web-UI, Live-APIs und ElegantOTA-Link.
wifi_config.h | Netzwerkkonfiguration.
wifi_manager.cpp / .h | WLAN-Aufbau; GeniusBulli mit fester IP, andere Netze per DHCP; kein mDNS.
ota_manager.cpp / .h | ArduinoOTA; ElegantOTA wird zusaetzlich ueber den Webserver bereitgestellt.
secrets.example.h | Vorlage fuer lokale WLAN-/OTA-Zugangsdaten; secrets.h wird nicht committed.
tools/SatAlign_ESP32_V3_InstallTest/SatAlign_ESP32_V3_InstallTest.ino | Eigenstaendiger Hardware-Diagnosesketch fuer Erstinbetriebnahme und Hardwareverdacht. Prueft Hardwarepfade getrennt von der normalen AUTO-Logik; danach fuer den Regelbetrieb wieder SatAlign_ESP32_V3.ino flashen.

# 14. Wichtige Web-Routen

Route | Aufgabe
/ | Hauptmenue
/center | Ausrichten / Mitte
/auto | Automatische Suche
/manual | Manuelle Steuerung
/status | Status / Diagnose
/troubleshooting | Troubleshooting
/update | ElegantOTA Firmware Update
/api/... | Live-APIs fuer RF, Hall, Suche und Ausrichten
/reset | Motoren stoppen, Neustart ausloesen

# 15. Test- und Inbetriebnahmehinweise

Vor der eigentlichen Inbetriebnahme sollten Taster, TFT, Hall-Sensoren, MPU6050, RF-Detector, beide Bewegungsrichtungen, STOP-Funktion, Web-UI und beide OTA-Wege einzeln geprueft werden. Fuer RF-/AUTO-Fehler ist der strukturierte AUTO_LOG-Block die bevorzugte Diagnosequelle.

Der InstallTest liegt bewusst unter tools/SatAlign_ESP32_V3_InstallTest/SatAlign_ESP32_V3_InstallTest.ino. Er ist fuer isolierte Hardwaretests gedacht und nicht fuer den regulaeren Betrieb. Bei unklaren Hall-, Motor-, Taster-, TFT-, MPU- oder RF-Problemen sollte deshalb zuerst der InstallTest verwendet werden, bevor die AUTO-Logik veraendert wird.

Testbereich | Pruefung bei Inbetriebnahme
Taster | MODE, PLUS und MINUS einzeln pruefen.
TFT-Display | Anzeige, Lesbarkeit, Menues und Versionsanzeige pruefen.
MPU6050 / Winkel | I2C-Verbindung, Stillstand, Offset und Winkelanzeige pruefen.
RF-Detector | RAW/FILTER/SIGNAL ohne und mit Receiver bzw. echtem Satellitensignal pruefen.
Azimut | Ost-/West-Bewegung, STOP und Richtungszuordnung pruefen.
Hall-Sensoren | Center, Ost und West einzeln ausloesen und Diagnose pruefen.
Elevation | Winkel +/-, STOP, Softlimits und Mechanik pruefen.
Web/WLAN/OTA | 192.168.4.15 im GeniusBulli-Netz, Web-UI, ArduinoOTA und /update pruefen.
InstallTest | Bei Erstinbetriebnahme oder Hardwareverdacht den separaten Sketch unter tools/SatAlign_ESP32_V3_InstallTest/ verwenden. Taster, TFT, Hall, MPU6050, RF sowie Motor-/STOP-Pfade einzeln pruefen; anschliessend Hauptfirmware wieder flashen.

Testart | Pruefpunkte
Offline | Menues, Taster, TFT, Motorstop, Hall-Zustaende und RF-Grundwerte.
Aussentest | Receiver an, grob Sueden, Suche starten, Kandidaten pruefen, PLUS/MINUS testen.
RF-Kalibrierung | RAW/FILTER/SIGNAL bei echtem Empfang protokollieren; aktueller Stand V3.1.5: Filter 0,50, AUTO-Minimum 80 %, Nutzerbewertung prozentbasiert.
AUTO-Log | Block AUTO_LOG_BEGIN bis AUTO_LOG_END fuer Analyse sichern.
OTA | ArduinoOTA ueber IP/Port 3232 und ElegantOTA ueber http://192.168.4.15/update pruefen; kein mDNS.

# 16. Troubleshooting

Die folgende Auswertung soll helfen, Fehler systematisch einzugrenzen. Vor der ersten Inbetriebnahme und nach groesseren Umbauten sollten Hardwarepfade manuell einzeln geprueft werden. Bei Problemen der automatischen Suche sollte zusaetzlich der komplette Block AUTO_LOG_BEGIN bis AUTO_LOG_END gesichert werden.

## 16.1 Schnellpruefung vor jeder Fehlersuche

- Sat-Receiver eingeschaltet?
- Antenne grob nach Sueden ausgerichtet?
- Web-UI erreichbar und richtige IP-Adresse verwendet?
- Hall-Sensoren in Status/Diagnose plausibel?
- RF ohne Antenne bzw. ohne Receiver als schwach/rot sichtbar?
- Manuelle STOP-Funktion getestet?

## 16.2 Typische Probleme und Massnahmen

Zur besseren Uebersicht ist die Fehlersuche in mehrere Themenbereiche aufgeteilt. Dadurch bleiben die Tabellen lesbarer und die Massnahmen koennen gezielter abgearbeitet werden.

### 16.2.1 Web, WLAN und OTA

Problem | Massnahme / Pruefung
Web-UI nicht erreichbar | Im GeniusBulli-Netz die feste IP 192.168.4.15 pruefen. Andere WLANs erhalten die Adresse per DHCP.
ArduinoOTA-Port fehlt | ESP/Arduino IDE im selben Netz, Serial-Ausgabe fuer IP und OTA Port 3232 pruefen. mDNS wird nicht verwendet; IP-basierte Verbindung bevorzugen.
ElegantOTA nicht erreichbar | http://192.168.4.15/update pruefen und sicherstellen, dass der Webserver gestartet ist.

### 16.2.2 RF, Receiver und Suche

Problem | Massnahme / Pruefung
RF bleibt schwach/rot | Receiver einschalten, Koax/RF-Tap/Sat-Splitter/DC-Blocker und AD8317 pruefen. Ohne Receiver liegt kein verwertbares Signal am RF-Detector an. Der DC-Blocker muss vor dem AD8317 sitzen, damit 13 V / 18 V nicht zum Detector gelangen.
RF ist schwach trotz TV-Bild | RAW/FILTER/SIGNAL protokollieren und reale Verkabelung, Splitter/Daempfung sowie RF-Kalibrierung pruefen. PLUS bleibt die Benutzerbestaetigung des Satelliten.
Falscher Satellit erkannt | MINUS druecken; Bereich wird abgelehnt bzw. die Suche laeuft weiter. Antenne grob neu pruefen.
Suche findet nichts | Receiver, grobe Sued-Ausrichtung, Winkel-Startwert und RF-Verkabelung pruefen. Danach Suche wiederholen.

### 16.2.3 Ausrichten, Hall-Sensoren und Azimut

Problem | Massnahme / Pruefung
Ausrichten startet nicht | Ost-/West-Endbereich aktiv oder Centerzustand blockiert. Web-UI-Warnung beachten und manuell vorsichtig in Gegenrichtung fahren.
Ausrichten zeigt sofort laeuft | Menue neu laden und Zustand pruefen. Die Fahrt darf erst nach Startbutton/MODE beginnen. Bei Wiederholung Runtime-Status im Serial Monitor kontrollieren.
Abbruch stoppt nicht sauber | STOP/Abbruch erneut pruefen. Wenn Motor weiterlaeuft: Rohausgaenge, Optokoppler und Treiberpfad testen.
Hall zeigt nicht korrekt | A3144, Magnetabstand, Pull-up, active-low-Logik und Rohpins pruefen. InstallTest nutzen und jeden Sensor einzeln ausloesen.
Center wird nicht erkannt | Magnetposition zum Center-Sensor pruefen. Sensor muss im richtigen mechanischen Bereich sicher schalten.
Ost/West-Endbereich wird nicht erkannt | A3144-Endsensoren und Magnetabstand pruefen. Bei aktiver Endlage muss die Web-UI hellrot warnen.

### 16.2.4 Winkel, Motoren und AUTO-Suche

Problem | Massnahme / Pruefung
Winkel springt oder driftet | MPU-Befestigung, Kabelzug, Offset und Filterwerte pruefen. Sensor muss fest mit der Antenne verbunden sein.
Winkel passt nicht zum realen Aufbau | DISPLAY_ANGLE_OFFSET_DEG mit realem Messwert oder bestem Sat-Empfang kalibrieren.
AUTO stoppt unplausibel | Kompletten AUTO_LOG-Block sichern. RF-Filter, 80-%-Mindestgrenze, Hall-Zustaende und BADSAT-Verlauf anhand der Daten pruefen.
AUTO faehrt bis Endbereich | Hall-Endsensoren, Richtungszuordnung und STOP-Verhalten pruefen. Endsensorereignis muss im seriellen Log sichtbar sein.

## 16.3 AUTO-Log fuer Suchdiagnose

Bei Problemen der automatischen Suche den kompletten seriellen Block von AUTO_LOG_BEGIN bis AUTO_LOG_END kopieren. Er enthaelt Zeit, Zustand, Richtung, RAW/FILTER/SIGNAL, DROP, Referenzwerte, Diagnose-AZPOS, Elevation, Hall-Zustaende, Mindestschwellen und BADSAT-Anzahl. Redundante periodische AUTO-Ausgaben sind in V3.1.4 bewusst reduziert.

Situation | Nutzen des AUTO-Logs / der Einzelpruefung
Motor reagiert nicht | Manuelle Richtung und STOP getrennt pruefen; AUTO-Log erst danach bewerten.
Hall-Sensoren unplausibel | Jeden Sensor einzeln ausloesen und H_C/H_E/H_W im Log vergleichen.
Winkel stimmt nicht | MPU, Offset und Stillstandswerte getrennt pruefen.
RF unplausibel | Receiver, DC-Blocker, Splitter, Adapter/Kabel sowie RAW/FILTER/SIGNAL vergleichen.
AUTO findet falsche/keine Kandidaten | Kompletten AUTO_LOG_BEGIN- bis AUTO_LOG_END-Block auswerten; MIN_RF, CENTER_MIN und BLOCKED beachten.

# Anhang: Konzeptionelle Darstellung der Antennenhalterung

Die folgende Abbildung zeigt beispielhaft den mechanischen Aufbau der Antennenhalterung mit Grundplatte, Schwenkmechanik, Elevationsantrieb und Antennenaufnahme.

Hinweis: Die Abbildung ist eine konzeptionelle Darstellung. Masse, Materialstaerken, Lagerpunkte und Befestigungen muessen am realen Aufbau separat geprueft werden.

SatAlign ESP32 V3 - Gesamtdokumentation

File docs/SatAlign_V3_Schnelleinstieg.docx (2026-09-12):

SatAlign V3 - Schnelleinstieg

Softwarestand: V3.1.5

V3.1.1: Firmware-Update wahlweise per ArduinoOTA aus der IDE oder per ElegantOTA im Browser unter /update.

Automatische Satelliten-Ausrichthilfe - Kurzbedienung

Stand V3.1.5 - RF-Filter 0,50 - AUTO-Kandidat ab 80 % - Web-Feinjustierung erweitert

Wichtig vor dem Start: Sat-Receiver einschalten und Antenne grob nach Süden ausrichten.

V3.1.5: RF-Anzeige und AUTO-Suche verwenden weiterhin dieselbe Prozentbewertung. Die normale AUTO-Kandidatenschwelle bleibt bei 80 %, die gemeinsame RF-Anzeige bei maximal 100 %. Nach einem separaten Vergleichstest mit Filterfaktoren 0,75, 0,50 und 0,25 wurde RF_FILTER_ALPHA von 0,75 auf 0,50 reduziert. Dadurch werden kleine Signalveraenderungen beim Feinjustieren schneller sichtbar, ohne die staerkere Unruhe von 0,25 zu uebernehmen. Auf der Seite Suchen steht der Prozentwert im Vordergrund: <80 % schwach, 80-<85 % brauchbar, 85-<95 % gut, >=95 % sehr gut. ADC/Spannung sind dort nicht als primaere Bedienwerte noetig und bleiben der Diagnose bzw. Feinjustierung vorbehalten.

1. Einschalten
• Anlage einschalten; kurz erscheint der START-/Südausrichtungs-Hinweis ohne Tastenbedienung.
• Danach wechselt das System ins Hauptmenü.
• Die Elevation wird nicht mehr in einem Boot-Zeitfenster eingestellt.

2. Grobe Vorbereitung

• Antenne mechanisch grob nach Süden stellen.

• Receiver muss eingeschaltet sein, sonst ist kein verwertbares Signal messbar.

• Wenn ein Endsensor aktiv ist: im Menü Manuell vorsichtig vom Endbereich wegfahren.

3. Mitte / Ausrichten
• Menü Ausrichten / Mitte einstellen öffnen.
• Lokal: PLUS/MINUS korrigieren die Elevation in kurzen Pulsen von ca. 250 ms; MODE startet die Mittenfahrt.
• Web-UI: „Ausrichten starten“ startet die Mittenfahrt direkt.
• ABBRUCH stoppt die Bewegung.

4. Suchen

• Menü Suchen öffnen und Suche starten.

• Ablauf: Mitte suchen -> Osten -> Westen -> zurück zur Mitte.

• Danach Winkel leicht ändern und die Suche bei Bedarf wiederholen.

5. Satellit gefunden?

• PLUS = richtiger Satellit bestaetigen.

• MINUS = falscher Satellit / weiter suchen.

• Hoeherer SIGNAL-%-Wert = staerkeres Signal; beim ADC gilt umgekehrt: kleiner = staerker.

6. AUTO-Log bei Problemen

• Bei unplausibler Suche den seriellen Block AUTO_LOG_BEGIN bis AUTO_LOG_END sichern.

• Der Block enthaelt RF-, Richtungs-, Hall-, Elevations- und BADSAT-Daten.

• Keine automatische Peak-/Signaloptimierung im stabilen Release V3.1.4.

7. Manuell

• Manuell Azimut: Ost / West fahren und mit STOP anhalten.

• Manuell Winkel: Winkel + / Winkel - fahren und mit STOP anhalten.

• Hall-Sensoren: Center grün, Ost/West rot.

8. Signal-Ampel

• Rot = Signal schwach.

• Gelb/Orange = brauchbar.

• Grün = gut bis sehr gut.

• Auch bei schwachem RF kann PLUS genutzt werden, wenn am TV ein Bild sichtbar ist.

Kurzregel: Receiver an, grob nach Sueden, Ausrichten, Suchen, Kandidat am TV pruefen. PLUS bestaetigt den richtigen Satelliten, MINUS verwirft ihn und setzt die Suche fort. Fuer die letzte Optimierung in der Web-UI auf Manuell wechseln. Unter den normalen AZ-/Winkel-Fahrbuttons stehen Fein - / Fein +. Zwischen diesen beiden Feinbuttons werden Signalstärke und Feinwert live angezeigt. Beim Oeffnen von Manuell wird automatisch eine neue Referenz gesetzt: AZ zeigt 0 -> +/-n Schritte; EL zeigt Referenzwinkel -> aktuellen Winkel und die Winkelaenderung. Reset-Buttons sowie Puls-/PWM-Werte werden in der Bedienansicht nicht angezeigt. Technisch fahren AZ und Elevation pro Klick 50 ms; Elevation bleibt bei PWM 90. Der Feinwert spreizt die Signalstärke von 80-100 % linear auf 0-100 % und dient nur als Anzeige-Lupe. AUTO und RF-Schwellen bleiben unveraendert. Die separate Signalbewertungs-/Diagnosekarte ist entfernt; der technische Status zeigt nur Motorzustand AZ/EL, Hall-Sensoren und EL-Winkel samt Softlimits.

Hardwareproblem? Den separaten InstallTest unter tools/SatAlign_ESP32_V3_InstallTest/SatAlign_ESP32_V3_InstallTest.ino verwenden. Er dient nur der Diagnose; danach wieder die Hauptfirmware SatAlign_ESP32_V3.ino flashen.

SatAlign V3 - Schnelleinstieg

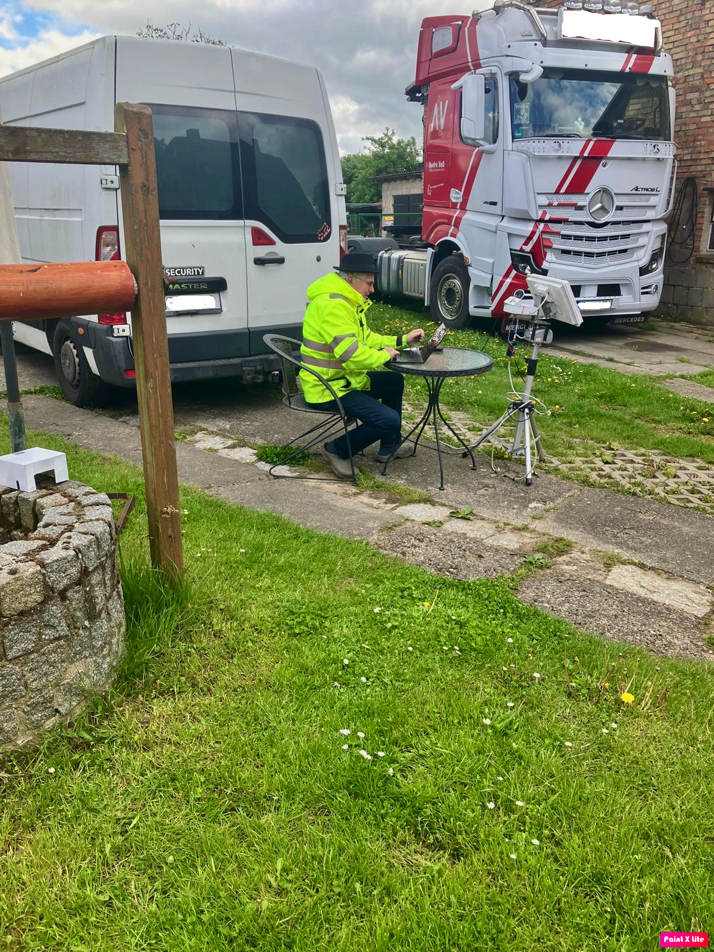
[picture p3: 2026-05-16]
images/Versuch_200.jpeg

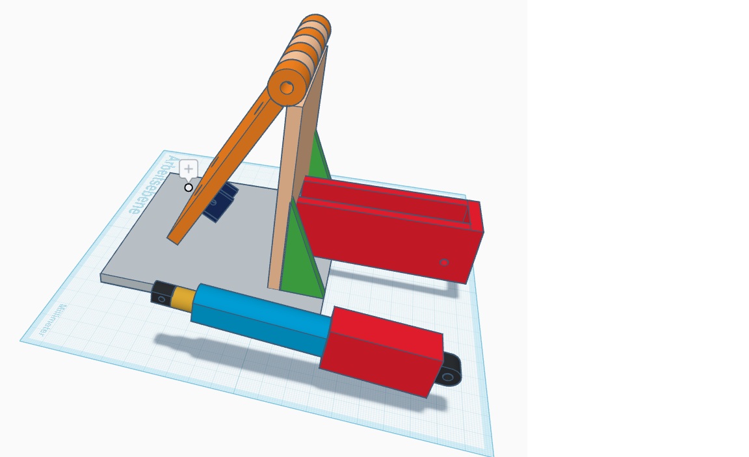
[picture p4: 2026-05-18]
images/Antennenhalterung.jpg

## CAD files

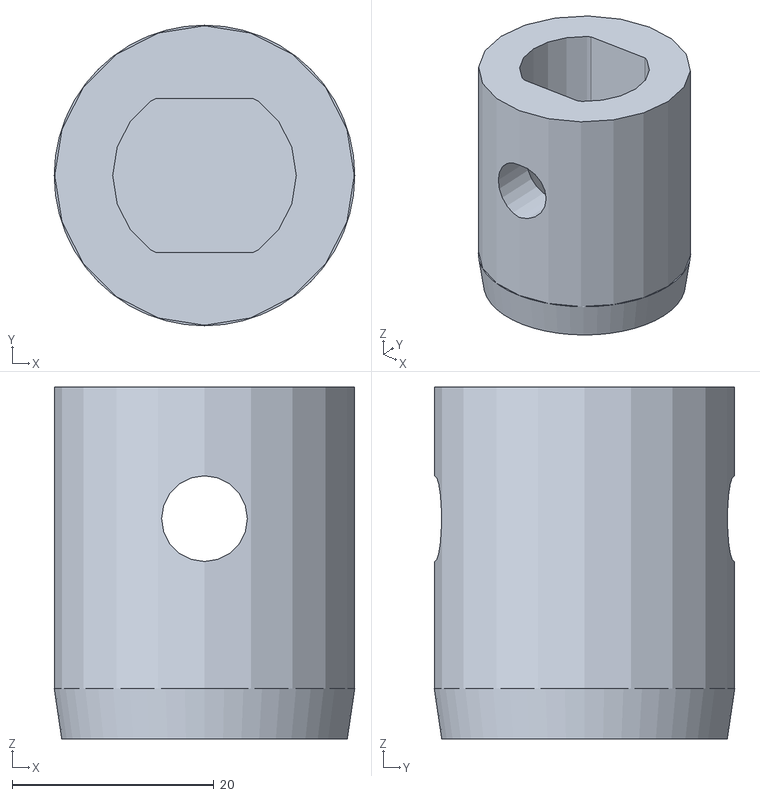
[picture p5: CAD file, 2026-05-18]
STL/DiSEqC_Adapter.stl
29.8 x 29.8 x 34.9

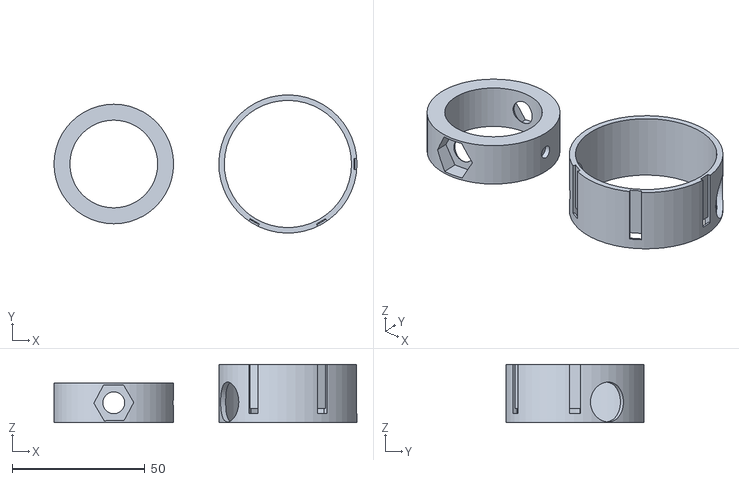
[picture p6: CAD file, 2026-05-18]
STL/Hall Ringe.stl
114.0 x 52.0 x 22.0

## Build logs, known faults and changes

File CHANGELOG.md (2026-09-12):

# Changelog

## V3.1.5 - current

- Manual fine-adjust Web UI reorganized for direct feedback while clicking.
- The manual fine-alignment controls now label the live values as user-facing `Signalstärke` and `Feinwert` instead of `RF` and `OPT`.
- A new fine-adjustment reference is set automatically when opening `Manuell`: AZ starts at `0` steps; EL stores the current MPU angle.
- Position display now shows the reference explicitly: AZ as `0 -> +/-n steps`; EL as `reference angle -> current angle (delta)`.
- Reset controls and pulse/PWM values were removed from the user-facing fine-adjustment rows; pulse settings remain centrally configurable in `settings.cpp`.
- The separate lower signal/diagnostic card was removed from the manual page; Signalstärke and Feinwert remain directly at the fine-step controls.
- Technical status is compacted to three rows: AZ/EL motor state, Hall sensors, and EL angle with soft limits; duplicate Web/Live state rows were removed.
- Search Web UI presents the actual RF percentage and quality label instead of voltage/ADC as the primary user-facing signal value; raw values remain available in diagnostic contexts.
- User-facing RF quality classes are derived from the common percentage scale: `<80 % = weak`, `80-<85 % = usable`, `85-<95 % = good`, `>=95 % = very good`. This classification is display-only; the AUTO candidate threshold remains 80 %.
- Main `SatAlign_ESP32_V3.ino` header now explicitly identifies firmware V3.1.5.
- Firmware version raised to 3.1.5. AUTO search logic, 80 % candidate threshold, RF normalization and tested motor-direction mapping are unchanged.

## V3.1.4 - stable

- RF filter changed from 0.75 to 0.50 after a reproducible RF/azimuth comparison test.
- Normal AUTO candidate minimum remains 80 %.
- RF display cap adjusted from 95 % to 100 %; AUTO candidate minimum remains unchanged.
- TFT, Web UI, serial diagnosis and AUTO search use the same RF percentage evaluation.
- Compact AUTO serial logging added and cleaned up for field diagnostics.
- Redundant periodic AUTO output suppressed while important events remain visible.
- Stable AUTO search logic retained; no experimental peak-return logic included.
- GeniusBulli uses fixed IP 192.168.4.15.
- ArduinoOTA and ElegantOTA are available in parallel.
- mDNS is not used.
- Legacy automatic "Signal optimieren" workflow removed from the active user flow.
- Existing `tools/SatAlign_ESP32_V3_InstallTest/` hardware diagnostic sketch retained and documented explicitly.
- Documentation aligned with current center/elevation behavior: PLUS/MINUS use short 250 ms pulses; obsolete 10-second boot-adjust window removed from documentation.

## V3.1.3

- Normal AUTO candidate threshold raised to 80 % based on field testing.

## V3.1.2

- RF strong reference adjusted to 700 ADC.
- Usable RF percentage display capped at 95 %.

## V3.1.1

- ElegantOTA added alongside ArduinoOTA.
- RF percentage calculation unified between display and AUTO search.

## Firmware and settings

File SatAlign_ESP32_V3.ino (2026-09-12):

/*
  SatAlign V3.1.5 - Hauptsketch
  ------------------------------------------------------------
  Startet Hardware, WLAN, OTA, Webserver, RF-Detector und Runtime.
  Der Sketch verbindet die Module, enthaelt aber moeglichst wenig eigene
  Fachlogik. Aktueller Projektstand: V3.1.5.
*/

/*
  SatAlign ESP32 - Hauptsketch
  Version: V3.1.5
  ---------------------------------------------------------------------------
  Einstiegspunkt des ESP32-Projekts.

  setup(): initialisiert Settings, Serial, Sensoren, TFT, WLAN, Web-UI und OTA.
  loop(): aktualisiert RF, Runtime, Display, Webserver, OTA und Heartbeat.

  Die eigentliche Bedien- und AUTO-Logik liegt bewusst in live_runtime.cpp.
*/
#include <Arduino.h>
#include <math.h>
#include <string.h>

#include "config.h"
#include "wifi_manager.h"
#include "web_server.h"
#include "ota_manager.h"
#include "settings.h"
#include "rf_detector.h"
#include "display_ui.h"
#include "pins.h"
#include "sensor_mpu6050.h"
#include "control_state.h"
#include "azimuth_control.h"
#include "elevation_control.h"
#include "live_runtime.h"

unsigned long lastHeartbeat = 0;

// V3.1.4 Diagnosebuild: kompakte RF-Messzeile fuer die reale Kalibrierung.
// Ausgabeintervall bewusst 500 ms, damit Messreihen im seriellen Monitor
// gut nachvollziehbar sind, ohne die Steuerlogik zu veraendern.
static unsigned long lastRfCalibrationDiag = 0;
static const unsigned long RF_CAL_DIAG_INTERVAL_MS = 500;

static float bestSignalNorm = 0.0f;
static char signalTextBuffer[32] = { 0 };

// V3.1.4: Eine einzige RF-Prozentbewertung im gesamten Projekt.
// Anzeige und AUTO-Logik verwenden beide rfGetSignalNorm()/rfGetSignalPercent().
// Dadurch kann die Anzeige nicht mehr einen anderen Prozentwert zeigen als
// die Kandidatenerkennung intern bewertet.
static const char* signalTextFromNorm(float norm) {
  const float percent = norm * 100.0f;

  // V3.1.5: dieselben sichtbaren Qualitaetsstufen wie in Web-UI/Runtime.
  if (percent >= RF_QUALITY_STRONG_MIN_PERCENT) return "sehr gut";
  if (percent >= RF_QUALITY_GOOD_MIN_PERCENT)   return "gut";
  if (percent >= RF_QUALITY_USABLE_MIN_PERCENT) return "brauchbar";
  return "schwach";
}

static UiMode currentUiMode() {
  if (!liveMpuReady()) {
    return UI_MODE_WARN;
  }

  if (liveAutoFailed()) {
    return UI_MODE_WARN;
  }

  if (controlMode == CONTROL_MAIN_MENU) {
    return UI_MODE_MENU;
  }

  if (controlMode == CONTROL_CENTER) {
    return UI_MODE_CENTER_ALIGN;
  }

  if (controlMode == CONTROL_AUTO) {
    if (liveAutoHasPeak()) {
      return UI_MODE_AUTO;
    }

    return UI_MODE_SEARCH;
  }

  if (azimuthIsPulseActive() || elevationIsPulseActive()) {
    return UI_MODE_SEARCH;
  }

  return UI_MODE_MANUAL;
}

static const char* currentElevationText() {
  return liveGetElevationStateText();
}

static const char* currentAzimuthText() {
  switch (azimuthGetDirection()) {
    case AZ_DIR_EAST:
      return "EAST >>";

    case AZ_DIR_WEST:
      return "WEST <<";

    default:
      return "STOP";
  }
}

static const char* currentAzimuthState() {
  return liveGetAzimuthStateText();
}

static const char* currentInfoText() {
  if (controlMode == CONTROL_MAIN_MENU || controlMode == CONTROL_CENTER) {
    return liveGetInfoText();
  }

  if (controlMode == CONTROL_AUTO) {
    return liveGetInfoText();
  }

  const char* liveInfo = liveGetInfoText();

  if (
    strncmp(liveInfo, "AZWARN|", 7) == 0 ||
    strncmp(liveInfo, "AUTO_SETUP|", 11) == 0
  ) {
    return liveInfo;
  }

  if (!rfIsReady()) {
    return "INFO: RF nicht bereit";
  }

  if (!rfHasValidSignalDrop()) {
    return "RF: Receiver/Signalweg pruefen";
  }

  return liveInfo;
}

static void updateDisplayFromLiveData() {
  DisplayData ui;

  const float signalVolts = rfGetPinVoltage();
  // V3.1.4: exakt dieselbe normierte RF-Bewertung wie in der AUTO-Logik.
  const float signalNorm = rfGetSignalNorm();

  if (signalNorm > bestSignalNorm) {
    bestSignalNorm = signalNorm;
  }

  ui.mode = currentUiMode();

  ui.signalVolts = signalVolts;
  ui.signalNorm = signalNorm;
  ui.signalBestNorm = bestSignalNorm;
  ui.signalText = signalTextFromNorm(signalNorm);

  ui.elevationDeg =
    liveMpuReady()
      ? liveGetRelativeAngleDeg()
      : 0.0f;

  ui.elevationText = currentElevationText();

  ui.azimuthText = currentAzimuthText();
  ui.azimuthState = currentAzimuthState();

  ui.infoText = currentInfoText();

  displayRender(ui);
}

void setup() {
  Serial.begin(SERIAL_BAUDRATE);
  delay(1000);

#if DEBUG_BOOT
  Serial.println();
  Serial.println("==================================");
  Serial.print("Selfsat Autotracker - V");
  Serial.println(FIRMWARE_VERSION);
  Serial.println("==================================");
#endif

  bool loadedFromFlash = initSettings();

#if DEBUG_BOOT
  if (loadedFromFlash) {
    Serial.println(
      "Settings aus Flash geladen. "
      "WARNUNG: In No-NVS-Version unerwartet."
    );
  } else {
    Serial.println(
      "Settings aus Code-Defaults gesetzt. "
      "Preferences/NVS wird nicht benutzt."
    );
  }
#endif

#if DEBUG_VERBOSE
  printSettingsToSerial();
#endif

  // ---------------------------------------------------
  // TFT
  // ---------------------------------------------------
  displayInit();

  displayShowStartupStatus(
    "Display bereit",
    "System initialisiert"
  );

  // ---------------------------------------------------
  // Runtime, Taster, Motoren und MPU6050
  // ---------------------------------------------------
  initLiveRuntime();

  const bool mpuBootOk = liveMpuReady();

  displayShowMpuBootTestResult(
    mpuBootOk,
    liveGetRelativeAngleDeg()
  );

  if (!mpuBootOk) {
    azimuthStop();
    elevationStop();

#if DEBUG_BOOT
    Serial.println(
      "BOOT ABGEBROCHEN: MPU6050/GY-521 fehlt "
      "oder konnte nicht initialisiert werden."
    );

    Serial.println(
      "Anlage stromlos machen, Sensor/Kabel "
      "pruefen und neu starten."
    );
#endif

    displayShowMpuFatalBootError();

    while (true) {
      delay(1000);
    }
  }

  // ---------------------------------------------------
  // Bekannter Hinweis zur groben Südausrichtung
  // ---------------------------------------------------
  // Während dieses Startbildschirms werden noch keine
  // Tastenfunktionen angezeigt.
  displayShowSouthAlignPrompt();

  // ---------------------------------------------------
  // WLAN
  // ---------------------------------------------------
  displayShowStartupStatus(
    "WLAN",
    "Verbindung wird aufgebaut"
  );

  wifiInit();

  // ---------------------------------------------------
  // OTA
  // ---------------------------------------------------
  displayShowStartupStatus(
    "OTA",
    "Dienst wird gestartet"
  );

  otaInit();

  // ---------------------------------------------------
  // Webserver
  // ---------------------------------------------------
  displayShowStartupStatus(
    "Webserver",
    "Dienst wird gestartet"
  );

  webServerInit();

  // ---------------------------------------------------
  // RF-Sensor
  // ---------------------------------------------------
  displayShowStartupStatus(
    "RF-Sensor",
    "Signalweg wird gestartet"
  );

  initRFDetector();

  // ---------------------------------------------------
  // Alle Initialisierungen abgeschlossen
  // ---------------------------------------------------
  // Erst jetzt wird dem Benutzer signalisiert, dass das
  // System Eingaben verarbeitet.
  displayShowSystemReady();

  // Danach wird das normale Hauptmenü mit seinen
  // Tastenhinweisen eingeblendet.
  liveCommandOpenMainMenu();
  updateDisplayFromLiveData();

#if DEBUG_BOOT
  Serial.println("RF-Test: Bitte Sat-Receiver einschalten.");

  Serial.println(
    "RF-Anzeige nutzt RF-Spannung; "
    "AUTO bewertet Signal dynamisch."
  );

  Serial.println("Live-Setup abgeschlossen.");
#endif
}

void loop() {
  wifiLoop();
  otaLoop();
  webServerLoop();

  rfUpdate();

  runLiveRuntime();

  updateDisplayFromLiveData();

  // ---------------------------------------------------
  // RF-Kalibrierdiagnose V3.1.4
  // ---------------------------------------------------
  // Diese Ausgabe verwendet exakt dieselben Mess- und Prozentwerte wie
  // Display und AUTO-Logik. Dadurch koennen reale ADC-Grenzwerte spaeter
  // ohne Schaetzung aus den Aussentests abgeleitet werden.
  // Im AUTO-Betrieb liefert serviceAutoSearchLog() bereits den kompakten,
  // strukturierten Messdatenstrom. Die normale RF_DIAG-Ausgabe wird dort
  // bewusst unterdrueckt, damit der kopierbare AUTO-Block nicht mit
  // redundanten Diagnosezeilen vermischt wird.
  if (!isAutoMode() && millis() - lastRfCalibrationDiag >= RF_CAL_DIAG_INTERVAL_MS) {
    lastRfCalibrationDiag = millis();

    Serial.print("RF_DIAG | RAW=");
    Serial.print(rfGetRawAdc());

    Serial.print(" | FILTER=");
    Serial.print(rfGetFilteredAdc(), 1);

    Serial.print(" | V=");
    Serial.print(rfGetPinVoltage(), 3);

    Serial.print(" | SIGNAL=");
    Serial.print(rfGetSignalPercent(), 1);
    Serial.print("%");

    Serial.print(" | DROP=");
    Serial.print(rfGetDropAdc(), 1);

    Serial.print(" | AUTO=");
    Serial.print(liveGetAutoStateText());

    Serial.print(" | MODE=");
    Serial.println(liveGetModeText());
  }

#if DEBUG_STATUS
  if (millis() - lastHeartbeat >= HEARTBEAT_MS) {
    lastHeartbeat = millis();

    Serial.print("STATUS | ");

    Serial.print(liveGetModeText());

    Serial.print(" | AUTO=");
    Serial.print(liveGetAutoStateText());

    Serial.print(" | RF=");
    Serial.print(rfGetSignalPercent(), 0);

    Serial.print("% | RAW=");
    Serial.print(rfGetRawAdc());

    Serial.print(" | DROP_ADC=");
    Serial.print(rfGetDropAdc(), 0);

    Serial.print(" | EL=");
    Serial.print(liveGetRelativeAngleDeg(), 1);

    Serial.println(" deg");
  }
#endif
}

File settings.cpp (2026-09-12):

/*
  SatAlign V3 - einstellbare Betriebswerte
  ------------------------------------------------------------
  Hier liegen die zentralen Test- und Kalibrierwerte des Projekts:
  - Standard-Winkel beim Start
  - Elevationskorrektur in den normalen Menues
  - RF-Grenzwerte aus den Aussentests

  Die Werte werden bewusst im Sketch gehalten und nicht dauerhaft in NVS
  gespeichert. Wenn im Test bessere Werte gefunden werden, werden sie hier
  nachvollziehbar geaendert und kommentiert.
*/

/*
  SatAlign ESP32 - settings.cpp
  ---------------------------------------------------------------------------
  Zentrale Code-Defaults des Projekts.

  Wichtig: Diese Version nutzt bewusst keine NVS-/Preferences-Speicherung.
  Aenderungen an Zielwinkeln, Limits oder RF-Parametern sollen bewusst hier
  bzw. im Sketch erfolgen, damit der Code die verbindliche Quelle bleibt.
*/
#include <Arduino.h>
#include "settings.h"
#include "config.h"

// =====================================================
// Globale Runtime-Werte
// =====================================================
//
// WICHTIG:
// Diese Datei ist die zentrale Stelle für alle globalen,
// veränderbaren Systemwerte, die nicht mehr als harte
// Konstanten im Code stehen sollen.
//
// Die Variablen werden hier:
//
// 1. definiert
// 2. mit Defaultwerten versehen
// 3. beim Start immer aus den Code-Defaults aufgebaut
// 4. nicht automatisch in Preferences/NVS gespeichert
//
// config.h enthält dazu nur die extern-Deklarationen.

// -----------------------------------------------------
// Allgemein
// -----------------------------------------------------

// Serielle Baudrate für Diagnose / Monitor
unsigned long SERIAL_BAUDRATE = 115200;

// Abstand zwischen den Heartbeat-Ausgaben im Hauptloop
unsigned long HEARTBEAT_MS = 2000;

// -----------------------------------------------------
// Betriebsmodi
// -----------------------------------------------------

// Startmodus des Systems nach dem Einschalten.
// Der Live-Code setzt später oft explizit den gewünschten Modus,
// aber der globale Startwert bleibt trotzdem hier zentral definiert.
ControlMode DEFAULT_CONTROL_MODE = CONTROL_MAIN_MENU;

// Historischer/ergänzender Timeout-Wert für manuelle Eingriffe.
// Aktuell ist er nicht das zentrale Steuerinstrument,
// bleibt aber als Systemparameter verfügbar.
unsigned long MANUAL_OVERRIDE_TIMEOUT_MS = 15000;

// -----------------------------------------------------
// Azimut
// -----------------------------------------------------

// Standardpuls für einfache manuelle Azimutkommandos
unsigned long AZ_PULSE_MS = 250;

// Zusätzlicher Intervallwert aus früheren Tests / Hilfsroutinen
unsigned long AZ_TEST_INTERVAL_MS = 2500;

// Allgemeine Azimut-Einschwingzeit
unsigned long AZ_SETTLE_MS = 300;

// Erster längerer Puls im gestuften Azimutlauf.
//
// FUER DEN AKTUELLEN ERSTEN PRAXISTEST bewusst deutlich erhoeht,
// damit der langsame Azimutmotor beim Anfahren moeglichst lange
// am Stueck durchlaufen kann, statt sofort in kurze Suchschritte
// zerlegt zu werden.
unsigned long AZ_FIRST_PULSE_ON_MS = 3000;

// Normale Schritt-Pulsdauer im gestuften Azimutbetrieb.
//
// Ebenfalls fuer den ersten Test stark vergroessert, damit die
// Azimutbewegung sich fast wie ein Durchlauf anfuellt.
// Die eigentliche Feinstufigkeit soll spaeter erst nahe am Ziel
// bzw. bei echter RF-Reaktion kommen.
unsigned long AZ_STEP_PULSE_ON_MS = 1200;

// Pause zwischen zwei Azimut-Schritten.
//
// Fuer den ersten Test stark reduziert, damit der Motor zwischen
// zwei Schritten kaum stehen bleibt und praktisch fast durchlaeuft.
unsigned long AZ_STEP_PULSE_OFF_MS = 20;

//
// Hall-Sensor-Logik:
//
// Die A3144-Ausgänge werden hier mit externen 10k Pull-ups auf 3,3V betrieben.
// Dadurch gilt:
// - ohne Magnetkontakt -> Eingang liegt auf HIGH
// - bei erkanntem Magneten -> Hall-Sensor zieht nach GND -> LOW
//
// Deshalb ist die Hall-Logik active-low.
//
bool AZ_HALL_ACTIVE_LOW = true;

//
// Die Hall-Sensoren hängen jetzt an GPIO34 / GPIO36 / GPIO39.
// Diese Eingänge bekommen ihre Pull-ups extern auf der Platine,
// deshalb sollen die internen Pull-ups des ESP32 hier NICHT verwendet werden.
//
bool AZ_HALL_USE_INTERNAL_PULLUP = false;

// Historischer Richtungsparameter fuer alte Homing-Funktionen.
// Die aktuelle Mittenfunktion verwendet ihre eigene getestete Start-/Richtungslogik.
AzimuthDirection AZ_HOME_FIRST_SEARCH_DIRECTION = AZ_DIR_EAST;

// -----------------------------------------------------
// Elevation
// -----------------------------------------------------

// Allgemeiner Elevations-Bewegungswert aus älteren Tests
unsigned long EL_MOVE_MS = 2000;

// Allgemeiner Elevations-Pausenwert
unsigned long EL_PAUSE_MS = 2000;
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

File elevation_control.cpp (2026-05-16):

/*
  SatAlign V3 - Winkel-/Elevationssteuerung
  ------------------------------------------------------------
  Kapselt die Bewegung des Linearantriebs fuer den Winkel. Softwarelimits,
  Schritt-/Pulsfahrten und Sonderfaelle werden hier zentral behandelt.
*/

/*
  SatAlign ESP32 - elevation_control.cpp
  ---------------------------------------------------------------------------
  Kapselt die Elevationsachse am L298N: Rohfahrt hoch/runter, Pulse, Stop
  und einfache Ziel-/Pulsverwaltung.

  Die manuelle Bedienung darf als Override fahren. Mechanische Endabschalter
  des Linearantriebs bleiben die letzte Schutzebene.
*/
#include <Arduino.h>
#include <math.h>

#include "pins.h"
#include "config.h"
#include "elevation_control.h"

namespace {
  // Startzeit des aktuell laufenden Pulses
  unsigned long pulseStartTime = 0;

  // Dauer des aktuell laufenden Pulses in Millisekunden
  unsigned long currentPulseDurationMs = 0;

  // true = es läuft gerade ein zeitgesteuerter Elevationspuls
  bool pulseActive = false;

  // Zuletzt verwendeter PWM-Wert.
  // Praktisch vor allem für Diagnose / Nachvollziehbarkeit.
  int activePwm = 0;

  // Aktuelle semantische Bewegungsrichtung:
  // EL_DIR_UP / EL_DIR_DOWN / EL_DIR_STOP
  ElevationDirection currentDirection = EL_DIR_STOP;
}

// Entspricht exakt der in deinem funktionierenden Test-Sketch bewiesenen Rohlogik.
//
// Wirkung:
// - beide Richtungsleitungen LOW
// - PWM/Enable = 0
//
// Das ist der softwareseitig stromlose Stop-Zustand der Elevationsachse.
void elevationStopRaw() {
  digitalWrite(PIN_EL_IN1, LOW);
  digitalWrite(PIN_EL_IN2, LOW);
  analogWrite(PIN_EL_ENA, 0);
}

// Rohbewegung in eine elektrische Richtung.
//
// WICHTIG:
// Diese Funktion bedeutet NICHT automatisch "angezeigter Winkel wird größer".
// Die semantische Zuordnung erfolgt weiter unten in applySemanticDirection().
void elevationUpRaw(int pwm) {
  digitalWrite(PIN_EL_IN1, HIGH);
  digitalWrite(PIN_EL_IN2, LOW);
  analogWrite(PIN_EL_ENA, pwm);
}

// Rohbewegung in die entgegengesetzte elektrische Richtung.
//
// Auch hier gilt:
// Raw-Richtung != automatisch semantische Höhenrichtung.
void elevationDownRaw(int pwm) {
  digitalWrite(PIN_EL_IN1, LOW);
  digitalWrite(PIN_EL_IN2, HIGH);
  analogWrite(PIN_EL_ENA, pwm);
}

// Setzt eine semantische Bewegungsrichtung auf die reale Roh-Ansteuerung um.
//
// WICHTIG:
// In deinem funktionierenden Testaufbau war die Mechanik gegenüber den
// Rohfunktionen invertiert:
//
// manualDriveUp()   -> elevationDownRaw(...)
// manualDriveDown() -> elevationUpRaw(...)
//
// Deshalb bleibt diese bewiesene Zuordnung hier erhalten.
// Das ist wichtig, damit die späteren Funktionen "hoch" und "runter"
// fachlich korrekt bleiben, auch wenn die elektrische Richtung invertiert ist.
static void applySemanticDirection(ElevationDirection direction, int pwm) {
  if (direction == EL_DIR_STOP) {
    elevationStopRaw();
    currentDirection = EL_DIR_STOP;
    activePwm = 0;
    return;
  }

  // Semantisch "hoch":
  // relativer Winkel soll größer werden
  if (direction == EL_DIR_UP) {
    elevationDownRaw(pwm);
    currentDirection = EL_DIR_UP;
    activePwm = pwm;
    return;
  }

  // Semantisch "runter":
  // relativer Winkel soll kleiner werden
  elevationUpRaw(pwm);
  currentDirection = EL_DIR_DOWN;
  activePwm = pwm;
}

// Initialisiert die Elevations-Hardware.
//
// Aufgaben:
// - Richtungsleitungen als Ausgänge setzen
// - PWM/Enable-Pin als Ausgang setzen
// - sicheren Stop-Zustand herstellen
void initElevation() {
  pinMode(PIN_EL_IN1, OUTPUT);
  pinMode(PIN_EL_IN2, OUTPUT);
  pinMode(PIN_EL_ENA, OUTPUT);
  elevationStop();
}

// Startet eine kontinuierliche semantische Bewegung nach oben.
//
// WICHTIG:
// Diese Funktion beendet einen evtl. aktiven Pulsmodus und
// schaltet in eine direkte Dauerbewegung um.
void elevationUp() {
  pulseActive = false;
  currentPulseDurationMs = 0;
  applySemanticDirection(EL_DIR_UP, EL_PWM_FAST);
}

// Startet eine kontinuierliche semantische Bewegung nach unten.
void elevationDown() {
  pulseActive = false;
  currentPulseDurationMs = 0;
  applySemanticDirection(EL_DIR_DOWN, EL_PWM_FAST);
}

// Stoppt die Elevation vollständig.
void elevationStop() {
  pulseActive = false;
  currentPulseDurationMs = 0;
  applySemanticDirection(EL_DIR_STOP, 0);
}

// Startet einen zeitlich begrenzten Puls nach oben.
//
// Die Bewegung endet nicht in dieser Funktion,
// sondern später über elevationUpdate().
void elevationPulseUp(unsigned long pulseMs, int pwm) {
  pulseStartTime = millis();
  currentPulseDurationMs = pulseMs;
  pulseActive = true;
  applySemanticDirection(EL_DIR_UP, pwm);
}

// Startet einen zeitlich begrenzten Puls nach unten.
void elevationPulseDown(unsigned long pulseMs, int pwm) {
  pulseStartTime = millis();
  currentPulseDurationMs = pulseMs;
  pulseActive = true;
  applySemanticDirection(EL_DIR_DOWN, pwm);
}

// Muss zyklisch aufgerufen werden, damit zeitgesteuerte Pulse sauber enden.
//
// Wenn die Pulsdauer abgelaufen ist, wird automatisch gestoppt.
void elevationUpdate() {
  if (!pulseActive) {
    return;
  }

  if (millis() - pulseStartTime >= currentPulseDurationMs) {
    elevationStop();
  }
}

// Liefert true, wenn aktuell ein zeitgesteuerter Puls aktiv ist.
bool elevationIsPulseActive() {
  return pulseActive;
}

// Prüft, ob ein gegebener Winkel innerhalb der softwareseitigen Softlimits liegt.
//
// WICHTIG:
// Das ist nur die normale Arbeitsgrenze der Software.
// Der Linearantrieb hat zusätzlich noch interne Endschalter als
// mechanische letzte Sicherheitsstufe.
bool elevationWithinSoftLimits(float currentAngle) {
  return (currentAngle >= ELEVATION_MIN_SOFT &&
          currentAngle <= ELEVATION_MAX_SOFT);
}

// Liefert die aktuelle semantische Bewegungsrichtung.
ElevationDirection elevationGetDirection() {
  return currentDirection;
}
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

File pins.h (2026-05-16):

/*
  SatAlign V3 - Pinbelegung
  ------------------------------------------------------------
  Diese Datei ist die verbindliche Hardware-Zuordnung fuer ESP32, TFT,
  MPU6050, RF-Detector, Hall-Sensoren und Motoransteuerung.
  Aenderungen an Pins immer hier zentral dokumentieren.
*/

#pragma once

// =====================================================
// AD8317 / AD8318 ADC
// =====================================================
// Analog-Eingang für den RF-Detektor.
// Der AD8317/AD8318 liefert eine analoge Spannung,
// die im Projekt zur Signalbewertung verwendet wird.
//
// WICHTIG:
// Dieser Pin ist ein reiner ADC-Eingang und wird nicht als
// digitaler Ausgang verwendet.
static const int PIN_AD8318_ADC = 35;

// =====================================================
// I2C / MPU6050
// =====================================================
// I2C-Datenleitung für den MPU6050
static const int PIN_I2C_SDA = 32;

// I2C-Taktleitung für den MPU6050
static const int PIN_I2C_SCL = 21;

// =====================================================
// Azimut über Optokoppler / SatAlign ESP32 Tastensimulation
// =====================================================
// Diese beiden Pins simulieren über Optokoppler die Tasten
// EAST und WEST am Azimut-/DiSEqC-Motor.
//
// WICHTIG:
// Hier wird nicht direkt ein Leistungs-Motor angesteuert,
// sondern nur ein Steuersignal über den Optokoppler gegeben.
static const int PIN_AZ_EAST = 22;
static const int PIN_AZ_WEST = 17;

// =====================================================
// Hall-Sensoren Azimut
// =====================================================
// Drei Hall-Sensoren für:
// - Mitte / Südrichtung
// - Ost-Endanschlag
// - West-Endanschlag
//
// Diese Eingänge werden von der Azimut-Logik verwendet für:
// - Referenzfahrt
// - Endanschlag-Schutz
// - Mittenerkennung
//
// HINWEIS:
// Aktuell ist die Software auf active-low vorbereitet.
// Je nach Verdrahtung / Pull-up-Konzept kann das in den Settings
// angepasst werden.
static const int PIN_AZ_HALL_CENTER     = 39;
static const int PIN_AZ_HALL_EAST_LIMIT = 34;
static const int PIN_AZ_HALL_WEST_LIMIT = 36;

// =====================================================
// Elevation über L298N
// =====================================================
// Ansteuerung des 12-V-Linearantriebs über einen L298N.
//
// IN1 / IN2 legen die Richtung fest.
// ENA bekommt ein PWM-Signal zur Freigabe bzw. Geschwindigkeitsvorgabe.
//
// WICHTIG:
// Die tatsächliche mechanische Bedeutung von "hoch" und "runter"
// ist im Code bewusst semantisch umgesetzt, da die Roh-Richtung
// im funktionierenden Testaufbau invertiert war.
static const int PIN_EL_IN1 = 26;
static const int PIN_EL_IN2 = 27;
static const int PIN_EL_ENA = 25;

// =====================================================
// TFT ST7735
// =====================================================
// SPI-Pins für das kleine ST7735-TFT.
//
// Beschriftung am Displaymodul / in vielen ST7735-Anleitungen:
// - SDA entspricht hier der SPI-Datenleitung MOSI
// - A0 entspricht hier der Steuerleitung DC
//
// Im Code bleiben die bestehenden Variablennamen bewusst unverändert,
// weil die verwendete Adafruit-ST7735-Bibliothek technisch mit MOSI/DC arbeitet.
//
// WICHTIG:
// TFT RST ist hier absichtlich nicht als GPIO definiert,
// weil das Display direkt mit dem ESP32-Reset verbunden ist.
static const int PIN_TFT_MOSI = 19;
static const int PIN_TFT_SCK  = 18;
static const int PIN_TFT_CS   = 14;
static const int PIN_TFT_DC   = 23;

// TFT RST direkt an ESP32 RST -> kein GPIO-Pin hier

// =====================================================
// 3-Taster-Bedienung
// =====================================================
// Grün   = MODE
// Weiß   = MINUS
// Schwarz= PLUS
//
// Bedienkonzept im Hauptmenue:
// - PLUS/MINUS -> Menuepunkt 1-3 waehlen
// - MODE kurz  -> gewaehlten Menuepunkt starten
//
// Bedienkonzept im manuellen Modus:
// - MODE kurz  -> AZIMUT / ELEVATION wechseln
// - PLUS/MINUS -> je nach gewaehlter Achse bewegen
//
// WICHTIG:
// GPIO35 und GPIO39 sind input-only.
// Diese Pins besitzen keine normale Ausgangsfunktion.
//
// Zusätzlich wichtig:
// Für die Taster sind externe 10k Pull-ups vorgesehen.
// Das steht hier ausdrücklich dabei, damit bei der späteren
// Leiterplatte oder Verdrahtung keine Unsicherheit entsteht.
static const int PIN_BTN_MODE  = 13;   // Grün
static const int PIN_BTN_MINUS = 16;   // Weiß
static const int PIN_BTN_PLUS  = 33;    // Schwarz

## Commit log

2026-05-16 Initial SatAlign ESP32 V3 project
2026-05-16 Add README.md for SatAlign ESP32 V3 project
    Added detailed project description, main functions, hardware overview, operation instructions, web UI details, and configuration guidelines.
2026-05-17 Revert "Detect RF candidate during auto center movement"
    This reverts commit 40401298c4d4d8d42be320a6473928fd59abf7d8.
    [live_runtime.cpp]
2026-05-17 Prepare SatAlign ESP32 V3.0.0 release
2026-05-18 Improve README with mechanical concept images
    [DiSEqC_Adapter.stl, Hall Ringe.stl]
2026-05-18 Display RF signal as percent and tighten center candidate threshold
    [display_ui.cpp, live_runtime.cpp, settings.cpp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]
